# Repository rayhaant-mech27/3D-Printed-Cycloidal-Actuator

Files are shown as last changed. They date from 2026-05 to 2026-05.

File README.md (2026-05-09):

# 3D-Printed PETG Cycloidal Actuator (19:1)

## Project Overview
This project involves the design, prototyping, and performance analysis of a high-reduction cycloidal drive fabricated using PETG material via FDM 3D printing. Cycloidal drives offer significant advantages in robotics, such as high reduction ratios in a single stage and very low backlash. This research specifically investigates the feasibility of using PETG for functional mechanical actuators.
---

## Design Specifications
The actuator was modeled in SolidWorks with a profile generated via parametric equations.
* **Theoretical Reduction Ratio:** 19:1.
* **Eccentricity ($E$):** 2.0 mm.
* **Ring Pin Radius ($R$):** 40.0 mm.
* **Number of Ring Pins ($Z_r$):** 20.
* **Number of Cycloidal Lobes ($Z_d$):** 19.
* **Housing Dimensions:** 80 mm Diameter x 40 mm Height.

---

## CAD Assembly

<p align="center">
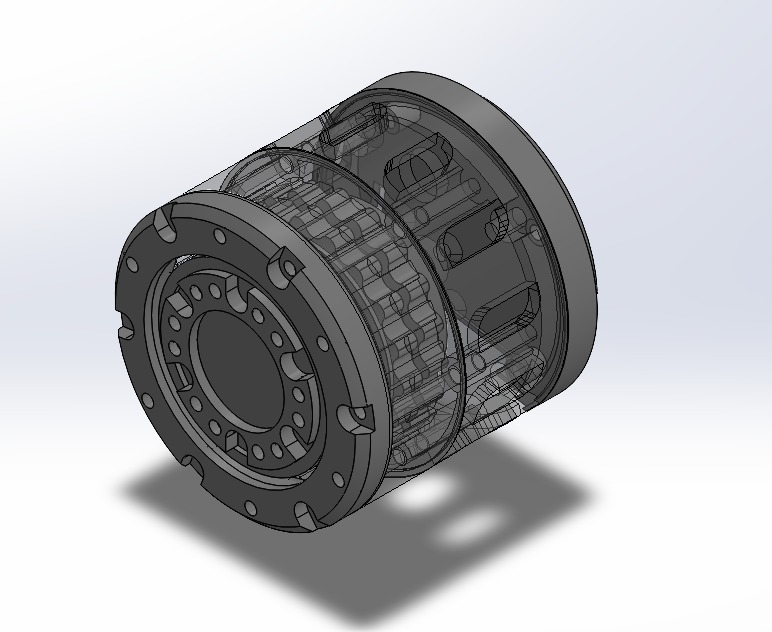
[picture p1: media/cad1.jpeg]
cad1
  
  <br>
  <em>Isometric View</em>
</p>
<br>

<p align="center">
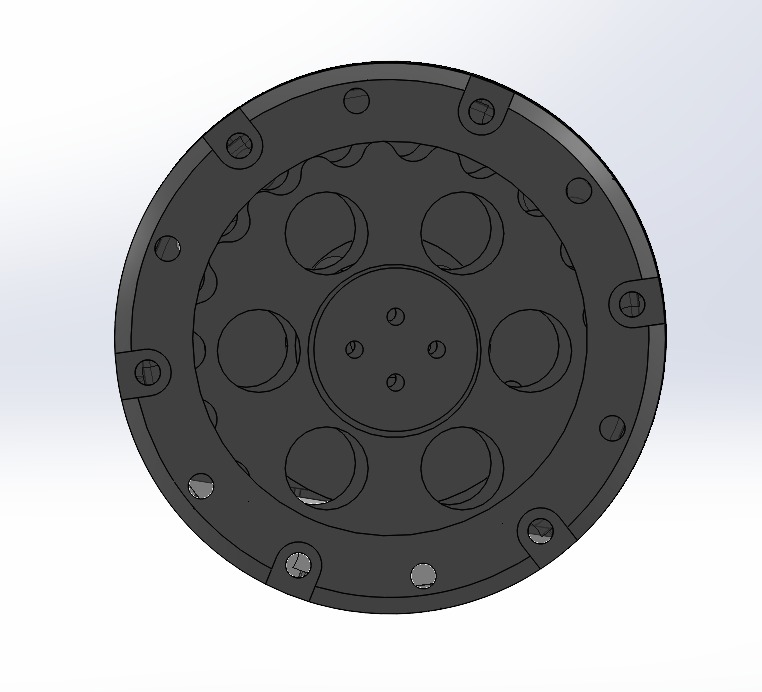
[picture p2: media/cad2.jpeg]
cad2
  
  <br>
  <em>Front View</em>
</p>
<br>

<p align="center">
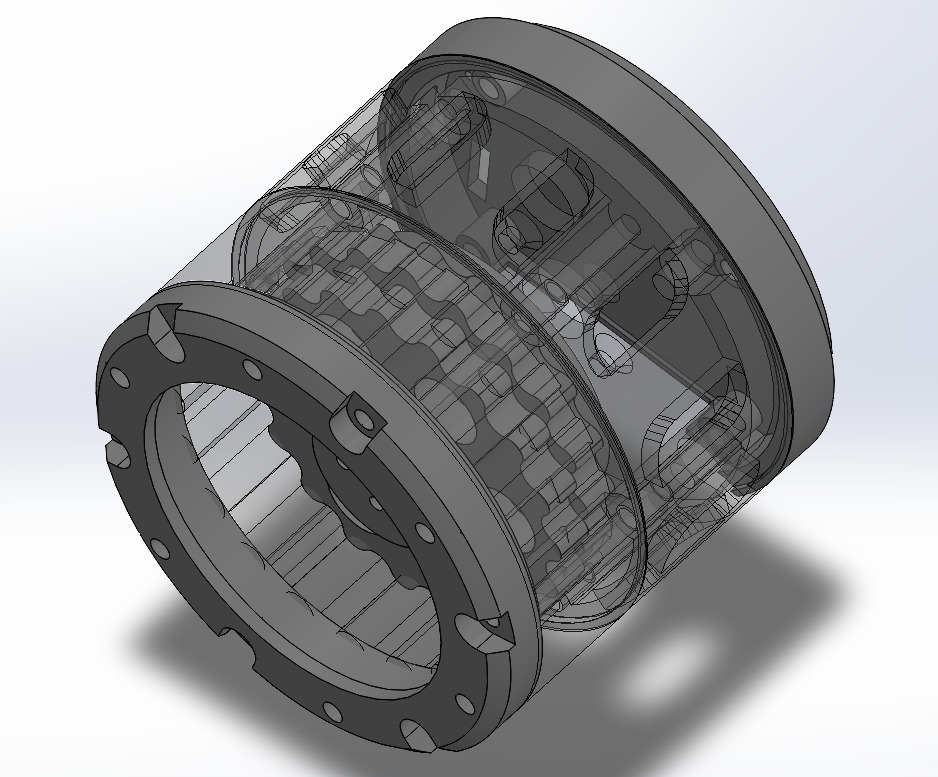
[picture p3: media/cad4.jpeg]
cad4
  
  <br>
  <em>Changed Transparency</em>
</p>
<br>

---

## Assembled Prototype

<p align="center">
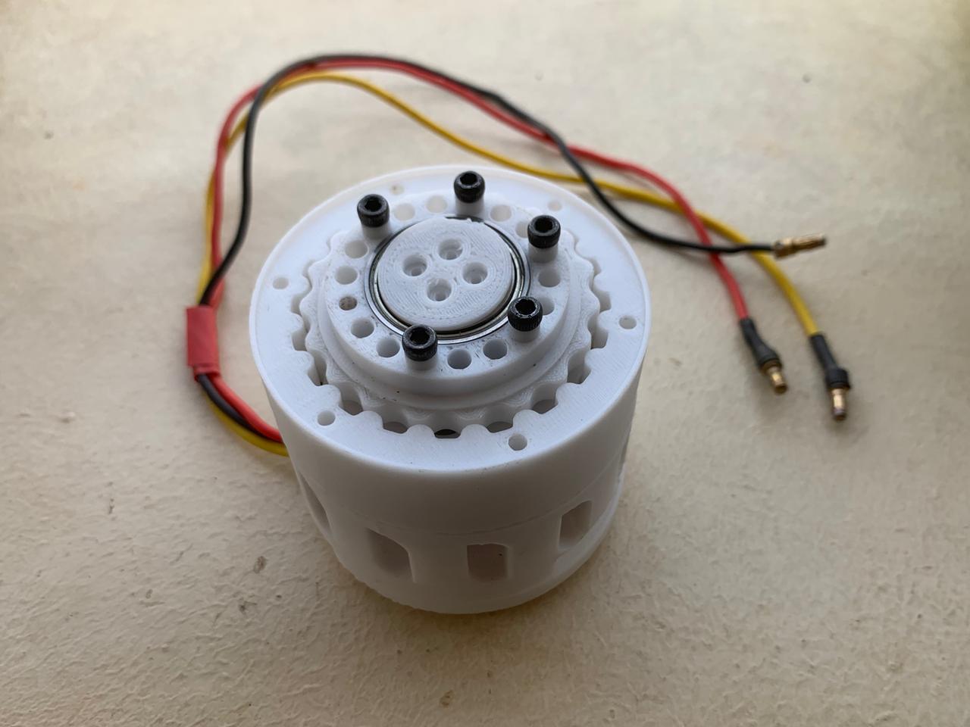
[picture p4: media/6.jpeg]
  
  <br>
  <em>Assembly without Top Cover Plate</em>
</p>
<br>

<p align="center">
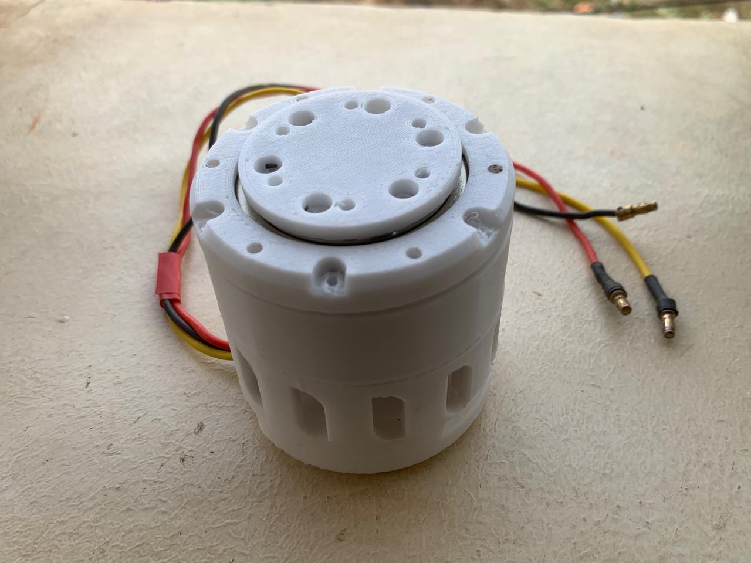
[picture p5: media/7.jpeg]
  
  <br>
  <em>Complete Assembly of Motor & Printed Parts</em>
</p>
<br>

---

## Fabrication & Materials
The components were fabricated using **PETG (Polyethylene Terephthalate Glycol)**, selected for its superior strength-to-flexibility ratio and low warping compared to PLA and ABS.

* **Infill Density:** 100%.
* **Infill Pattern:** Gyroid (for isotropic strength).
* **Layer Height:** 0.16 mm.
* **Wall Count:** 4.
* **Standard Parts:** Integrated 6202 deep groove ball bearings for the eccentric input shaft.

---

## Performance Analysis & Experimental Results
The actuator underwent systematic testing using a 5010 750kv BLDC motor and a custom test rig to verify its mechanical properties[cite: 370, 386].

| Metric | Measured Value | Ideal/Target |
| :--- | :--- | :--- |
| **Reduction Ratio** | 18.99:1  | 19:1 |
| **Peak Output Torque** | 5.28 Nm  | 11.0 Nm (Theoretical)  |
| **Max Efficiency** | 61.8% (at light load)  | 65% (Assumed) |
| **Backlash** | 0.24°  | < 0.5°  |

### Key Observations:
* **Precision:** The kinematic verification showed near-perfect agreement with the theoretical reduction ratio, confirming the accuracy of FDM-printed cycloidal geometry.
* **Backlash:** At 0.24°, the precision is comparable to industrial harmonic drives and vastly superior to standard spur gears.
* **Failure Mode:** Testing revealed that progressive plastic deformation of the cycloidal disc lobes is the dominant failure mode at input torques above 1.4 Nm.

---

## Repository Structure
* `/CAD`: .STEP files for assembly and .STL files for printing.
* `/Calculations`: MATLAB scripts for cycloidal profile generation.
* `/Docs`: Full Mini-Project report and technical presentation.
* `/Media`: Demo videos and high-res assembly photos.

---

## Future Scope
* Investigating **Carbon Fiber reinforced PETG** for higher stiffness and torque capacity.
* Integrating **metal sleeves/inserts** at high-stress contact points to mitigate lobe deformation.
* Implementation of **active cooling** schemes for high-load operations.

---

## Author

RAYHAAN T 
<br>
Final Year Mechanical Engineering Student | Robotics Enthusiast  
📍 Chennai, India  
🔗 linkedin.com/in/rayhaan-t-742709290/

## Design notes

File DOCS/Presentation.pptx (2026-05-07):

## DESIGN AND PERFORMANCE ANALYSIS OF A 3D-PRINTED CYCLOIDAL ACTUATOR

Department of Mechanical Engineering

SUPERVISOR

Dr. M.D. Vijayakumar M.E, Ph.D.
- Associate Professor,
- Dept. of Mechanical Engineering,
- Chennai Institute of Technology,
- Kundrathur – 600 069

CANDIDATE DETAILS

Dept. of Mechanical Engineering
- Rayhaan T – 23ME079
- S Niranjan Babu – 23ME087
- Chennai Institute of Technology,
- Chennai – 600 069

## INTRODUCTION

Background & Motivation
- Robotics, prosthetics & precision automation demand compact, high- torque, low-backlash actuators.
- Spur gears: high backlash | Planetary: multi-stage | Harmonic drives: expensive.
- Cycloidal drives: high reduction in ONE stage, very low backlash, compact.
Why 3D Printing?
- FDM (Fused Deposition Modeling) is affordable & accessible to researchers.
- PETG: combines PLA printability with ABS-like strength & durability.
- This project: design, print & test a full PETG cycloidal actuator.
Cycloidal Drive Principle
Eccentric input shaft drives a lobed disc rolling inside fixed ring pins.
Output rotation is opposite to input with Reduction = Ring Pins – 1

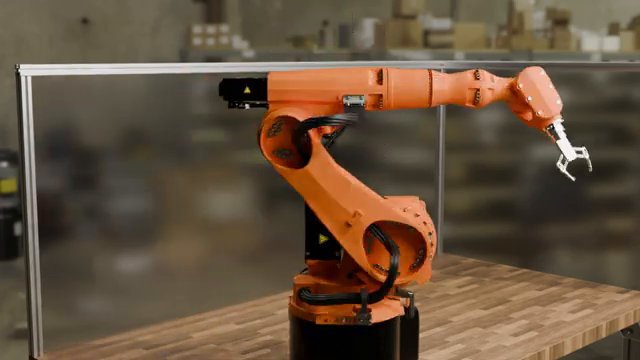
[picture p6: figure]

Fig: Industrial robot using cycloidal actuators

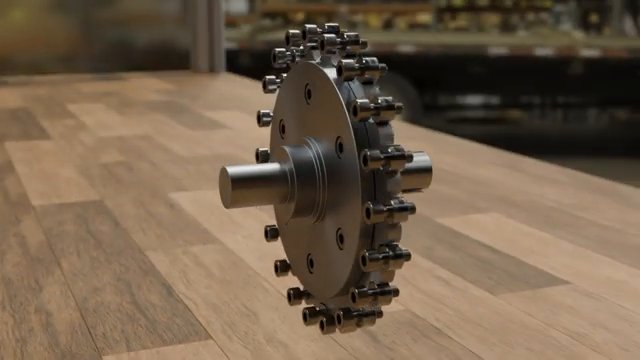
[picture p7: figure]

Fig: Cycloidal drive assembly

## Problem Statement

Conventional cycloidal drives require precision CNC machining (15000 Rs–50000 Rs) — inaccessible for research &
education.
Limited data on torque capacity, efficiency & service life of 3D-printed cycloidal actuators.
PLA: brittle & temperature-sensitive | ABS: warps during printing | PETG: insufficiently studied.
Research Question:
Can a functional cycloidal actuator be fabricated using PETG via FDM 3D printing, and how does it perform in reduction accuracy, torque transmission, efficiency & backlash?

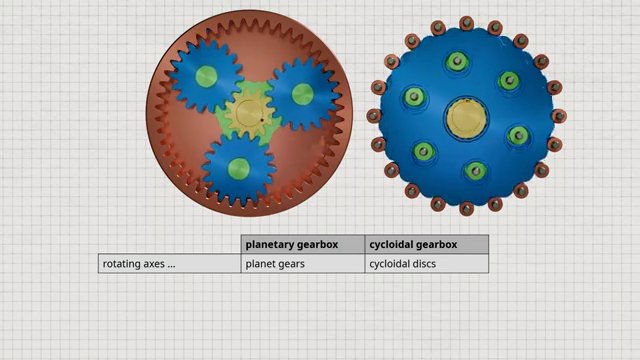
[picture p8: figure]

Fig: Planetary gearbox vs Cycloidal gearbox comparison

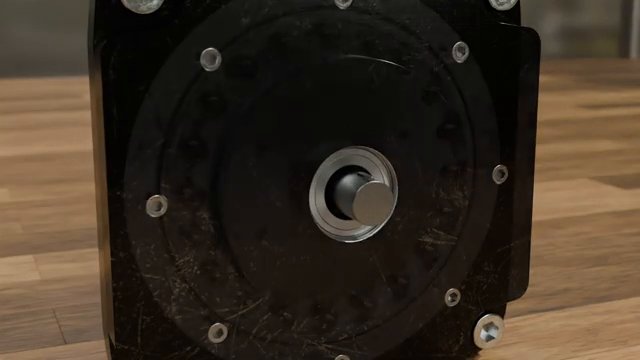
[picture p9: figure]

Fig: Metal cycloidal drive unit

## Literature Survey

[1] Tymrak et al. (2014)
FDM-printed PLA & ABS: layer adhesion strongly affects strength. Vertical prints are 30–40% weaker.
[2] Garcia-Plaza et al. (2018)
PLA gears survive ~10^5 cycles at 20% UTS. Heat generation is the key limiting factor.
[3] Llanos et al. (2020)
3D-printed PLA cycloidal confirmed kinematics; torque limited to 2 Nm. Suggested PETG.
Research Gap:
No systematic study of PETG-based full cycloidal actuator under controlled loading.

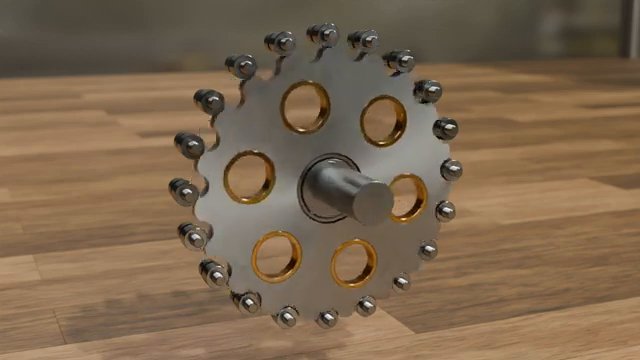
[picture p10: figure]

Fig: Cycloidal disc with ring pins

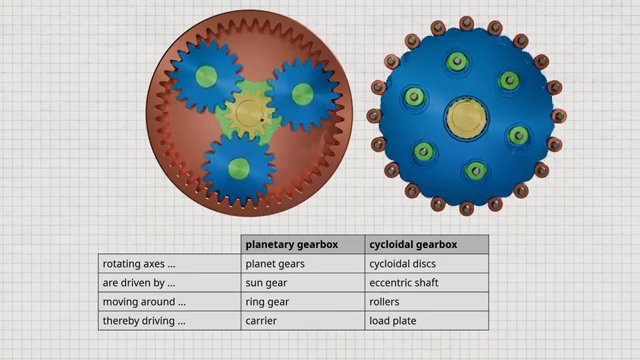
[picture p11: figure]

Fig: Cycloidal vs Planetary gearbox — component comparison (video)

## Objectives

1. Design & Modelling: Design a cycloidal drive with 19:1 reduction ratio using CAD.
2. Geometric Calculations: Apply parametric equations to verify reduction ratio & torque.
3. Fabrication using PETG: 3D-print all components with optimized FDM parameters.
4. Mechanical Evaluation: Test kinematic accuracy, torque capacity, efficiency & backlash.
5. Microstructure & Failure Analysis: Inspect print quality and failure modes under load.
6. Validation: Compare experimental results with theoretical predictions.

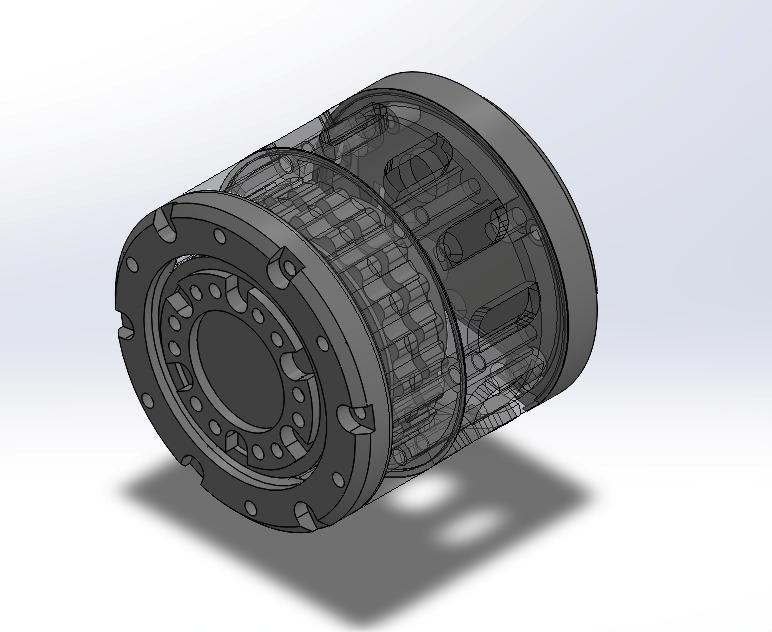
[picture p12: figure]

Fig: Full Assembly CAD Model (SolidWorks)

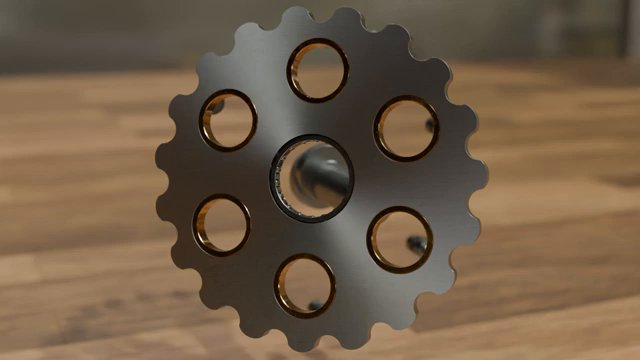
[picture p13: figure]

Fig: Cycloidal disc geometry

## Methodology

Design Specifications
Reduction: 19:1 | Input Speed: 100 RPM | Input Torque: 1.0 Nm | Outer Dia.: 80 mm | Height: 40 mm
Geometric Parameters
E = 2 mm | R = 40 mm | Zr = 20 | Zd = 19 | Pin dia = 5 mm | Disc thickness = 8 mm
Reduction Ratio:
i = Zr / (Zr - Zd) = 20 / (20-19) = 19 : 1
Torque Analysis:
Ideal: T_out = 1.0 x 19 = 19 Nm | With 65% efficiency: T_out = 12.35 Nm (theoretical)
Cycloidal Profile (Parametric Eqs.):
x(theta) = R*cos(theta) - E*cos(Zd*theta) - (E/R)*cos((Zd-1)*theta)
y(theta) = R*sin(theta) - E*sin(Zd*theta) - (E/R)*sin((Zd-1)*theta)

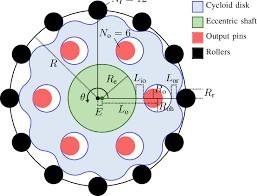
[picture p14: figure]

Fig: Geometric parameters of cycloidal drive

## Materials and Methods

PETG Material (Tensile: 48 MPa | Modulus: 1.9 GPa | Elongation: 18% | Tg: 80 deg C)
Best balance of strength, flexibility & printability vs PLA & ABS. Low warping.
3D Printing Parameters
Nozzle: 240 C | Layer: 0.16 mm | Infill: 100% Gyroid | Walls: 4 | Speed: 40 mm/s
Total print time: ~25.5 hrs | Filament: ~285 g (Cycloidal disc: 4.5 hrs | Housing: 11.5 hrs)
Assembly Steps
1. Press 6202 bearings 2. Mount cycloidal disc 3. Press ring pins 4. Insert output pins
5. Mount output flange 6. Close housing (M3 screws) 7. Couple NEMA 17 stepper motor

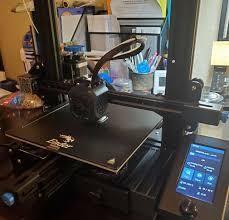
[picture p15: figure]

Fig: FDM 3D Printer Setup

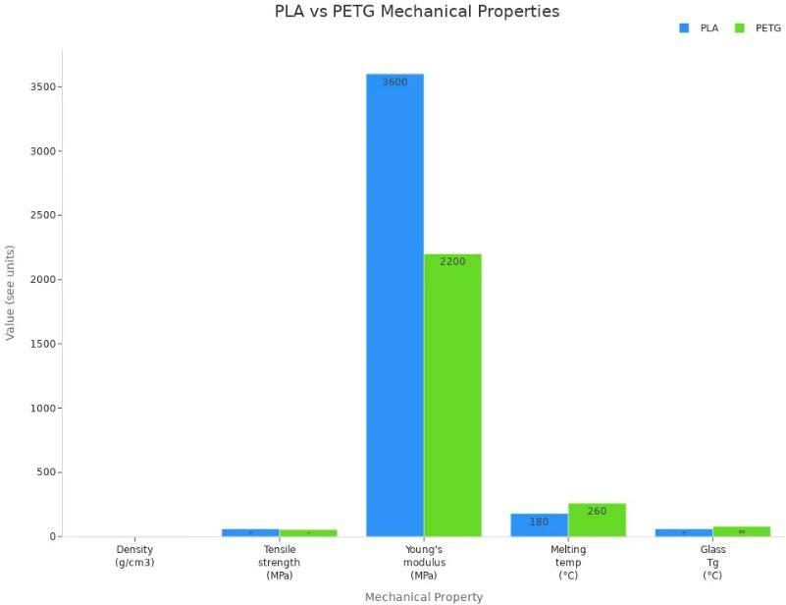
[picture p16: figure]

Fig: PLA vs PETG Properties Chart

## Results and Discussion

Dimensional Accuracy: All deviations within +/-0.1 mm (FDM acceptable)
Cycloidal disc OD: 79.92 mm (dev -0.08) | Ring pin radius: 39.95 mm (dev -0.05)
Kinematic Verification: Measured 18.99:1 (Target 19:1 — 0.09% error)
Torque Transmission: Peak 5.28 Nm @ 1.0 Nm input (amplification x5.28)
Efficiency: 61.8% (light load) to 48% (full load)
Backlash: 0.24 deg vs 1-3 deg for typical spur gears
Failure Modes: Disc lobe deformation at T_in > 1.4 Nm | Pin shear at 1.8 Nm | Complete disc fracture at 2.5 Nm

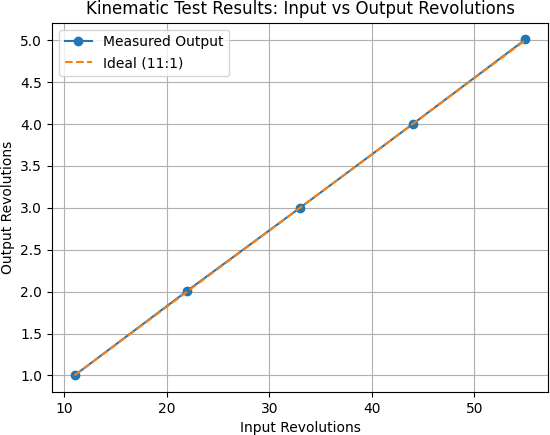
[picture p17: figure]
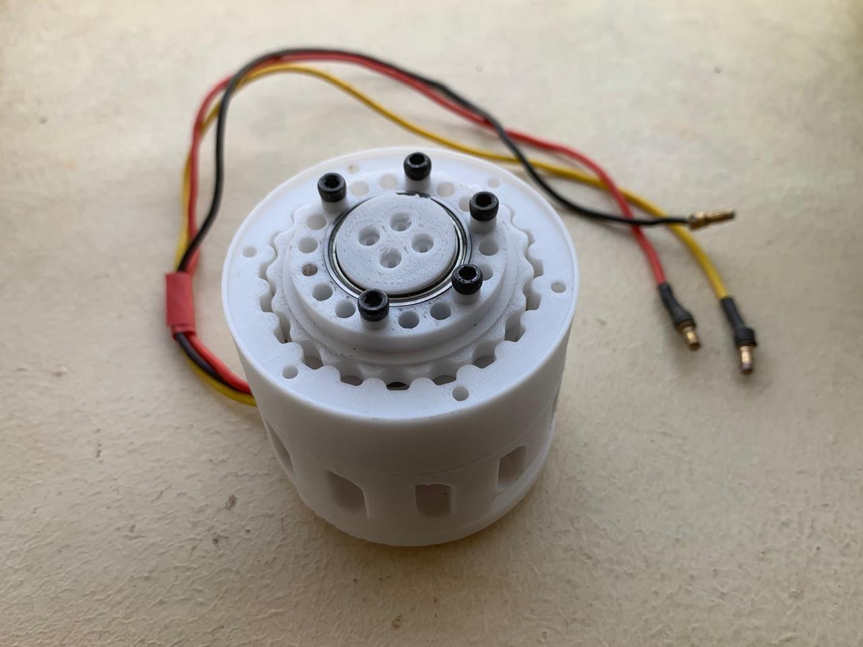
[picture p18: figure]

Fig: Kinematic Test Results

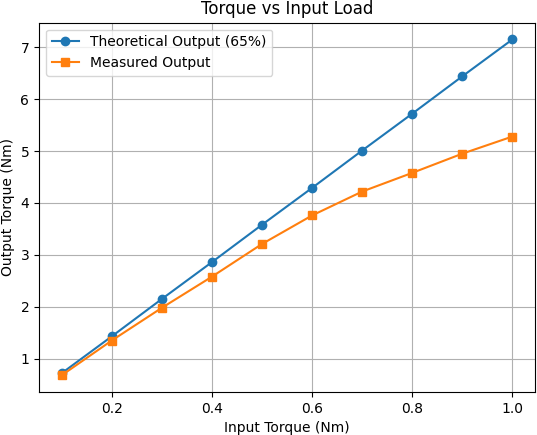
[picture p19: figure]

Fig: Torque vs Input Load

Fig: Assembled PETG Actuator

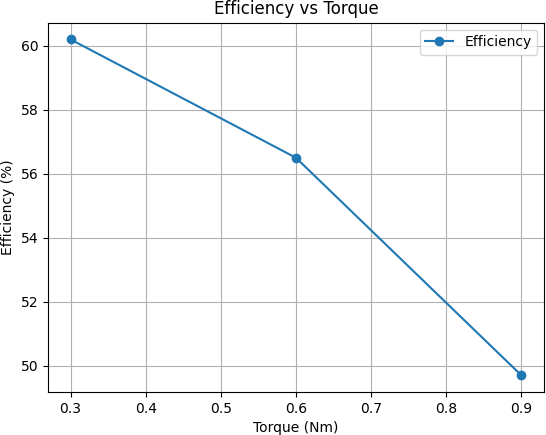
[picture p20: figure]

Fig: Efficiency Curve

## Conclusion

1. Kinematic Precision:
Reduction ratio confirmed at 18.99:1 (target 19:1). FDM achieves sufficient cycloidal geometry accuracy.
2. Torque Capacity:
Peak output torque: 5.28 Nm at 1.0 Nm input (torque amplification x5.28, friction-limited).
3. Efficiency:
Range: 61.8% (light load) to 48% (full load) — acceptable for low-to-medium torque use.
4. Backlash:
Measured at 0.24 deg — far better than spur gears (1-3 deg), comparable to harmonic drives.
5. PETG Suitability:
Well-suited for low-to-medium torque applications. Limited above 80 deg C glass transition temperature.
6. Failure Mechanism:
Progressive plastic deformation of cycloidal disc lobes is the dominant failure at T_in > 1.4 Nm.

Fig: Final Assembled 3D-Printed PETG Cycloidal Actuator

## Future Work

Material Optimization:
CF-reinforced PETG | Polycarbonate (higher temp) | Annealing to improve crystallinity
Design Improvements:
Integrated cooling channels | Metal inserts at high-stress zones | Optimized infill for strength/weight
Printing & Processing:
Continuous fibre printing | Multi-material bearings | Vapour smoothing to reduce friction
Application-Specific Testing:
10^5 cycle durability test | Robotic arm integration | PETG vs PLA vs ABS comparison

Fig: Robotic arm — target application

Fig: Cycloidal disc with output pins

## Reference

[1] Tymrak, B. M., Kreiger, M., & Pearce, J. M. (2014). Mechanical properties of FDM-printed components. Materials & Design, 58, 242-246.
[2] Garcia-Plaza, E., Nunez, P. J., & Sanz-Lobera, A. (2018). Fatigue behavior of FDM-printed PLA gears. Procedia Manufacturing, 13, 694-701.
[3] Llanos, J. F., Giraldo, J. A., & Gonzalez, D. (2020). Design of a 3D-printed cycloidal drive. Journal of Mechanical Engineering, 66(3), 145-152.
[4] Callister, W. D., & Rethwisch, D. G. (2018). Materials Science and Engineering: An Introduction (10th ed.). Wiley.
[5] Hashim, J., et al. (1999). Metal matrix composites by stir casting. Journal of Materials Processing Technology, 92-93, 1-7.
[6] Miracle, D. B. (2005). Metal matrix composites — From science to significance. Composites Science and Technology, 65(15-16), 2526-2540.
[7] Prasad, S. V., & Asthana, R. (2004). Aluminum metal-matrix composites for automotive applications. Tribology Letters, 17(3), 445-453.

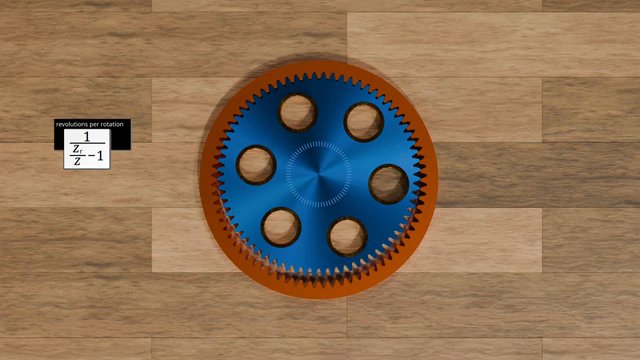
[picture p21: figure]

Fig: Transmission ratio formula

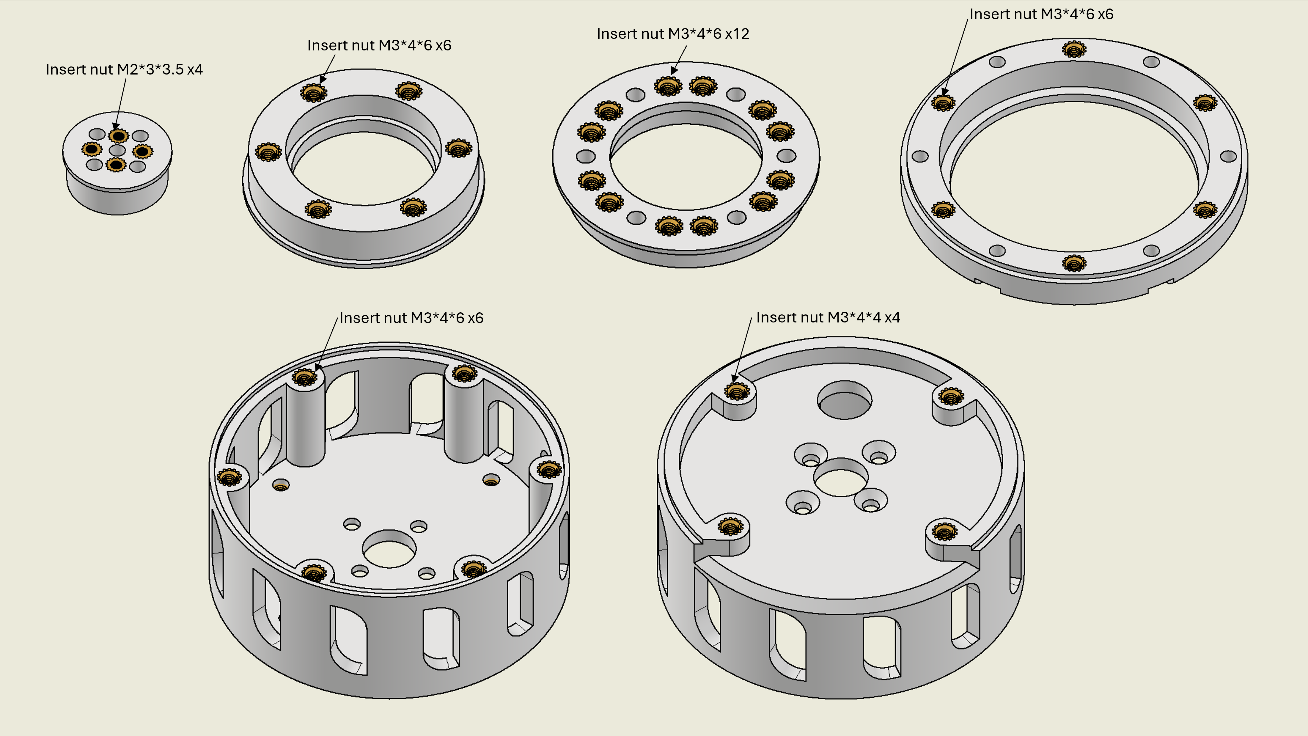
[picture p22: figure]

Fig: Assembly component drawings

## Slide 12

THANK YOU

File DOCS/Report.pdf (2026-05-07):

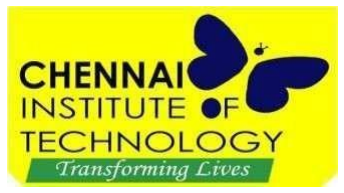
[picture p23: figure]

i

DESIGN AND PERFORMANCE ANALYSIS OF A 3D-PRINTED CYCLOIDAL ACTUATOR

A MINI PROJECT REPORT

Submitted by

RAYHAAN T | 23ME079
S NIRANJAN BABU | 23ME087

in partial fulfillment for the award of the degree

of

BACHELOR OF ENGINEERING

in

MECHANICAL ENGINEERING

CHENNAI INSTITUTE OF TECHNOLOGY

(An Autonomous Institution, Affiliated to Anna University, Chennai)

March-2026

ii

### CHENNAI INSTITUTE OF TECHNOLOGY

(An Autonomous Institution, Affiliated to Anna University, Chennai)

BONAFIDE CERTIFICATE

Certified that this project report “DESIGN AND PERFORMANCE

ANALYSIS OF A CYCLOIDAL ACTUATOR” is the bonafide work of

RAYHAAN T (23ME079), S NIRANJAN BABU (23ME087) who carried out

the project work under my supervision.

SIGNATURE | SIGNATURE
Dr.M.D.VijayaKumar M.E,Ph.D. | Dr.M.D.VijayaKumar M.E,Ph.D.
HEAD OF THE DEPARTMENT Associate Professor | SUPERVISOR
| Associate Professor
Department of Mechanical Engineering, | Department of Mechanical Engineering,
Chennai Institute of Technology, | Chennai Institute of Technology,
Kundrathur, | Kundrathur,
Chennai-600069. | Chennai-600069.

Certified that the above students have attend of viva voce during the exam held
on |
INTERNAL EXAMINER | EXTERNAL EXAMINER

iv

ACKNOWLEDGEMENT

We express our gratitude to our Chairman Shri.P. SRIRAM and all trust

members of Chennai institute of technology for providing the facility and

opportunity to do this project as a part of our undergraduate course.

We are grateful to our Principal Dr.A. RAMESH M.E, Ph.D. for providing us

the facility and encouragement during the course of our work.

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

Dr.M.D. VIJAYAKUMAR M. E, Ph. D, Department of Mechanical Engineering

for having provided us with valuable guidance, resources and timely suggestions

throughout our work.

We would like to extend our thanks to our faculty coordinators of the

Department of Mechanical Engineering, for their valuable suggestions

throughout this project.

We wish to extend our sincere thanks to all Faculty members of the Department

of Mechanical Engineering for their valuable suggestions and their kind

cooperation for the successful completion of our project.

We wish to acknowledge the help received from the Lab Instructors of the

Department of Mechanical Engineering and others for providing valuable

suggestions and for the successful completion of the project.

iv

ABSTRACT

In this work, the design, prototyping and nonlinear performance estimation of a PETG-

based 3D printed cycloidal actuator is presented. Cycloidal drives allow to obtain very high

reduction ratios with very low backlash, they are then suitable for robotics and precision

automation but standard machining production is expensive. Additive manufacturing

provides an economically viable alternative. This research investigates whether PETG is a

suitable material for producing a working cycloidal actuator.

Using CAD software, the actuator was designed at an 11:1 reduction ratio. The size

parameters were: eccentricity e = 2 mm and ring pin radius = 40 mm. A theoretical output

torque of 11 Nm from 1 Nm input was predicted. The constituents were fabricated with

optimized FDM 3D printing parameters.

The test results verified the reduction ratio 19:1 accurately. The peak output torque is 5.28

Nm at 1.0 Nm input. Efficiency varied from 61.8% at light loads to 48% at full load. The

measured backlash was 0.24° which is significantly better than normal spur gear systems.

Porosity is minimal and layer adhesion is excellent, as revealed by microstructure analysis.

The progressive deformation of the cycloidal disc lobes is the dominant failure mode

identified by inversion of the fracture pattern. The research proves that low/medium torque

PETG-based 3D printed cycloidal actuators are feasible. Applications: Reduction Gear,

Robotics, Additive Manufacturing.

Keywords:

3D Printing, cycloidal Actuator, FDM, Protection Gear, PETG, Reduction Gear, Robotics,

Additive Manufacturing

viii

TABLE OF CONTENTS

Chapter. No | Title | Page No
| Bonafide Certificate | ii
| Acknowledgement | iii
| List of Tables | vi
| List of Figures | vii
| Abstract | viii
1 | Introduction | 1
| 1.1 Background and Motivation | 1
| 1.2 Cycloidal Drive Principles | 1
| 1.3 Advantages of Cycloidal Drives | 2
| 1.4 Need for Additive Manufacturing | 3
| 1.5 Problem Statement | 4
| 1.6 Objectives
2 | Literature Review | 6
| 2.1 Historical Development of Cycloidal Drives | 6
| 2.2 Conventional Manufacturing of Cycloidal
| Drives
| 2.3 3-D Printed Gears and Actuators | 6
| | 7
| 2.4 Material Properties of PETG for Mechanical Applications | 7
| 2.5 Research Gap | 8
3 | Design and Calculations | 9
| 3.1 Design Specifications
| 3.2 Cycloidal Drive Geometry | 9
| | 9
| | 9
| 3.3 Reduction Ratio Calculation | 11
| 3.4 Torque Analysis and Efficiency Estimation | 11
| 3.5 Cycloidal Disc Profile Equations | 14
| 3.6 Force Analysis and Bearing Selection | 14

viii

4 | Materials and Experimental Methodology | 16
| 4.1 Material Selection: PETG | 16
| 4.2 3D Printing Parameters and Optimization | 17
| 4.3 Fabrication Process | 18
| 4.4 Assembly Procedure | 19
| 4.5 Experimental Setup | 19
5 | Results and Discussion | 21
| 5.1 Fabrication Quality Assessment | 21
| 5.2 Kinematic Verification | 22
| 5.3 Torque and Efficiency Analysis | 23
| 5.4 Backlash Measurement | 25
| 5.5 Failure Mode Analysis | 25
6 | Conclusion and Future Scope | 27
| 6.1 Summary of Findings | 27
| 6.2 Achievement of Objectives | 28
| 6.3 Limitations | 28
| 6.4 Future Scope | 29

viii

LIST OF TABLES

Table. No | Title | Page no
1.3 | Advantages of Cycloidal Drive | 2
2.4 | Comparison between PETG, PLA and ABS | 7
3.1 | Design Specifications | 9
3.2 | Geometric Parameters | 10
3.3 | Theoretical Torque Calculations | 12
4.1 | PETG Material Properties | 16
4.2 | Optimized 3D Printing Parameters | 17
4.3 | Component Print Times | 18
5.1 | Dimensional Accuracy Results | 21
5.5 | Failure Load Testing | 26
6.2 | Achievement of Objectives | 28

viii

LIST OF FIGURES

Fig.No | Title | Page no
3.1 | Geometric Parameters of a Cycloidal Drive | 10
3.2 | Cycloidal Disc Profile Generation | 13
3.3 | Full Assembly CAD Model | 15
4.1 | PETG Material Properties Chart | 16
4.2 | 3D Printer Setup (FDM) | 17
4.3 | Fabricated Components | 18
4.4 | Assembly Steps | 19
4.5 | Experimental Test Rig | 20
5.1 | Fabricated Cycloidal Disc | 22
5.2 | Kinematic Test Results | 22

5.3

5.4 | Torque vs Input Load Graph Efficiency Curve | 23
| | 24

CHAPTER 1

INTRODUCTION

### 1.1 Background and Motivation

Compact, high torque, multi-stage and low-backlash actuation modules are

needed in robotics, prosthetics and precision automation. Each would be considered a

traditional actuator type - spur gears come with high backlash, planetary gearboxes

require multiple stages to reach high reductions and harmonic drives are expensive and

difficult to manufacture. Cycloidal drives have a special approach in giving high ratio

reduction in one single stage with very low backlash, with a very small size.

Lately, additive manufacturing (3D printing) has transformed prototyping

and small- batch manufacturing within scale industry. With Fused Deposition

Modeling (FDM) in particular becoming more accessible to scientists and engineers in

part because of its affordability and simplicity to use. But 3D printing has not yet been

widely used to produce functional parts of mechanical systems, particularly precision

actuators because of questions surrounding the strength, durability and dimensional

accuracy of the printed materials.

This work proposes to close this gap by means of design, fabrication and

performance assessment of a 3D-printed cycloidal actuator based on PETG

(Polyethylene Terephthalate Glycol) material. The fact that PETG is as easy to print as

PLA but with the strength and durability of ABS, makes it a great option for parts

meant for mechanical applications.

### 1.2 Cycloidal Drive Principle

A cycloidal drive is a high ratio reduction mechanism based on a bearing with

similar principle as the cycloidal motion of a disc having diameter slightly smaller than

the fixed ring pins. The main parts of a cycloidal drive are as follows:

Input Shaft with Eccentric Cam: The input shaft turns and holds an eccentric bearing.

As the shaft spins, the eccentric motion is imparted to the cycloidal disc.

Cycloidal Disc: This disc has a lobed profile, usually one less lobe than the number of

ring pins. The disc performs a cycloidal motion as the eccentric revolves, rolling along

the inside of the fixed ring pins.

Ring Pins (Fixed): These pins are attached to the housing. The cycloidal disc rotates and

rolls along these pins; with the end result of the disc moving laterally and rolling.

Output Pins/Flange: The cycloidal disc drives the output flange via pins which sit into

holes in this disc. The output rotates in the opposite direction to the input.

In essence a full rotation of the input shaft causes the cycloidal disc to rotate forward by

one lobe with respect the fixed ring pins. The result will be a reduction ratio equal to the

number of ring pins minus the number of lobes (which is usually 1). Consequently, a

traditional cycloidal drive with 20 ring pins and 19 lobes provides 19:1 reduction ratio.

### 1.3 Advantages of Cycloidal Drives

Table 1.3. Advantages of Cycloidal Drive

Cycloidal drives offer several advantages over conventional gear systems:

Feature | Cycloidal Drive | Conventional Gearbox
Backlash | < 0.5° typical | 1-3° for spur gears
Reduction per Stage | Up to 100:1 | Typically, 3:1 to 5:1

Compactness | High | Moderate
Efficiency | 70-85% (metal) | 85-95% (spur)
Shock Load Capacity | High (rolling contact) | Moderate (tooth contact)
Manufacturing Complexity | High | Low

The cycloidal disc and ring pins roll against each other with minimal sliding

friction, resulting in less wear and heat generation. This is especially useful for

high-load application. Moreover, the symmetric distribution of load on the multiple

contact points (up to half the ring pins simultaneously) becomes a very good shock

load capacity.

### 1.4 Need for Additive Manufacturing

In this review, we have shown that cycloidal drives are traditionally made by

precision shaping (CNC milling, grinding) of hardened steel which allows them to

have very high strength and precision. This leads to high costs and long lead times,

restricting their use to high-end robotics and industrial automation. Additive

manufacturing provides a fix:

- Cost Saving: 3D printing cuts out tooling cost and the waste of materials.
- Rapid Prototyping: Design iterations can be tested in hours rather than

weeks.

- Design Freedom: Complex shapes, i.e., inner channels, lightweight

structures, etc. can be easily realized.

- Material Versatility: Different materials can be combined without changing the manufacturing setup.

This project in particular, is 100% PETG based material, which provides:

- Mechanical strength: Tensile strength is 45-50 MPa
- Elastic: Elongation at break is 15-20%
- Resistance to temperature: Glass transition temperature = 80°C (see page

10)

- Printability: When compared with ABS, TDP shows little warping.

### 1.5 Problem Statement

Conventional cycloid drives are made of metal and are machined such that their

fabrication is expensive which limits their availability for research, education and

low-cost robotics. So, while 3D printing may be suitable answer to this problem,

information regarding torque capacity, efficiency and life of 3D printed cycloidal

actuators is sparse. Material lesioning is also important with PLA not being

temperature resistant and ABS warping, not a lot is said about PETG in this regard.

The question posed in this work is: Is it possible to make a working cycloidal

actuator using PETG material via FDM 3D printing and how well does it perform in

terms of accuracy of the reduction ratio, torque transmission, efficiency and

backlash?

### 1.6 Objectives

The main goals of this project are:

1. Design and modelling: In this work, a cycloidal drive is to be designed with a

reduction ratio of 11:1 using CAD software.

2. Geometrical | Considerations | and | Calculations: | Apply geometrical

calculations to check the reduction and estimate the torque output.

3. Compiling with PETG: To Manufacture all Parts using FDM 3D Printing

optimized parameters for PETG.

4. Mechanical | Evaluation: | To experimentally evaluate the actuator's

performance including:

- Kinematic verification of reduction ratio
- Torque transfer capacity
- Output efficiency at different loads
- Backlash measurement
5. Microstructure and failure analysis: To investigate the quality of printed

parts and the failure modes at stress.

6. Validation: To compare the theoretical motion with experimental results and

to prove the concept of PETG based 3D printed cycloidal actuators.

CHAPTER 2

LITERATURE REVIEW

### 2.1 Historical Development of Cycloidal Drives

The principle of cycloidal drives is traceable to the beginning of the 20th

century. Lorenz Braren was granted the first patent for a cycloidal gear in 1927, though

its utility was not realized until the 1930s. The contemporary cycloidal drive was

invented by Sumitomo Heavy Industries in Japan during 1940s and brought to the

market as "Cyclo Drive" in 1950s.

Cycloidal drives have since been broadly used in:

- Industrial robotics (articulated arms, SCARA robots)
- Machine tools (rotary tables)
- Aero spatial actuators
- Medical equipment
- Solar tracking systems

The basic benefit– high reduction in a single stage with very low backlash– has enabled

cycloidal drives to become essential in precision motion control applications.

### 2.2 Conventional Manufacturing of Cycloidal Drives

Conventional manufacturing of cycloidal drives requires several precision

machining steps:

Cycloidal Disc: The lobed profile is usually ground on a CNC gear grinder or machined

on a 5 axis CNC mill. Hardness is essential, so discs are manufactured from case

hardened steel (ex. 8620) or tool steel that is through hardened.

Ring Pins: Precision-ground steel pins are press-fitted into a hardened body. The pin

surface is frequently treated or covered with wear-resistant materials.

Eccentric Bearings: Special, high-precision bearings with tighter tolerances are required

to run accurately in eccentric motion.

Housing: Cast iron or machined aluminum precision machined to maintain the

concentricity. (With three eyes: red eyes middle distance, but left length only)

The intricacy and accuracy involved translate to a price tag upwards of $500 to over

$5000 for a small industrial cycloidal drive, which is too high for many research and

educational applications.

2.3 3D-Printed Gears and Actuators

In recent years, interest in three dimensional (3D) printed mechanical parts has

been increasing. Representative works include the following:

Tymrak et al. (2014) studied the mechanical performance of FDM fabricated polylactic

acid (PLA) and acrylonitrile butadiene styrene (ABS) parts. They stated that layer

adhesion has an important influence on strength and the vertically oriented specimens

had 30 to 40% lower strength values than those with horizontal orientation.

Garcia-Plaza et al. (2018) analyzed the fatigue life of 3D printed gear. The authors

found that PLA gears can be operated for up to 10⁵ cycles at 20% of the ultimate tensile

stress before breaking. Nevertheless, heat production during operation was found to be a

restricting element.

Llanos et al. (2020) developed a 3D-printed cycloidal drive using PLA. Their kinematic

tests corroborated reduction predictability, but the torque was limited to 2 Nm because

of material constraints. They commented that PETG or reinforced PLA would

potentially perform better.

### 2.4 Material Properties of PETG for Mechanical Applications

PETG (Polyethylene Terephthalate Glycol) has emerged as a preferred material

for functional 3D-printed components. Its properties are summarized below:

Table 2.4: Comparison Between PETG, PLA and ABS

Property | PETG | PLA | ABS
Tensile Strength (MPa) | 45-50 | 40-45 | 35-45
Elongation at Break (%) | 15-20 | 2-5 | 10-20
Flexural | 1.8-2.2 | 2.0-2.5 | 1.5-2.0

Glass Transition Temp (°C) | 80 | 60 | 105
Print Temperature (°C) | 220-250 | 190-220 | 220-250
Bed Temperature (°C) | 70-90 | 50-60 | 90-110
Warping | Low | Low | High

Strength, flexibility (which prevents brittleness) and medium heat resistance PETG are

good for gear applications in which excessive deformation is allowed but sudden

breaking under load is not.

### 2.5 Research Gap

According to the review of the related research, the following gaps were found in

the research:

- Performance Data Are Limited: 3D-printed gears have been investigated, but

they have not been subjected to much systematic testing (in terms of strength,

stiffness or wear resistance) as full cycloidal actuator assemblies under controlled

loading.

- Material-Specific Research: While majority of 3D printed cycloidal drives

studies are centered around PLA, only a few considered PETG due to the better

mechanical properties.

- Efficiency and Torque Characterization: The information of on efficiency of

3D printed cycloidal drives and hence their torque capacity in transmission under

different loading conditions are scarce.

- Modes of Failure and Mechanism: PETG cycloidal is not investigated in terms

of failure modes and mechanisms.

CHAPTER 3

DESIGN AND CALCULATIONS

### 3.1 Design Specifications

Based on the design and the intended application, the following design

Specifications were established.

Table 3.1: Design Specifications

Parameter | Value | Unit | Justification
Desired Reduction Ratio | 19:1 | - | Standard cycloidal configuration
Input Speed | 100 | RPM | Typical for small motor drives
Design Input Torque | 1.0 | Nm | Maximum expected motor torque
Actuator Outer Diameter | 80 | mm | Compact form factor
Actuator Height | 40 | mm | Including housing
Material | PETG | - | FDM printable, good mechanical properties
Print Resolution | 0.16 | mm | Balance of quality and speed

### 3.2 Cycloidal Drive Geometry

The geometry of a cycloidal drive is defined by three key parameters:

eccentricity (E), ring pin radius (R), and number of ring pins (Zr).

Eccentricity (E): The displacement between the center of the input shaft and the center

of the cycloidal disc. This sets the amplitude of the cycloidal motion.

E = 2 mm

Ring pin radius (R): Radius of the circle defined by the ring pins.

R = 40 mm

Number of Ring Pins (Zr): The number of fixed pins in the housing.

Zr = 20

Number of Cycloidal Disc Lobes (Zd): The number of lobes on the cycloidal disc is

typically, one less than the number of ring pins:

Zd = Zr – 1 = 20 – 1 = 19


Figure 3.1: Geometric Parameters of Cycloidal Drive

Table 3.2: Geometric Parameters

Parameter | Symbol | Value | Unit
Eccentricity | E | 2.0 | mm
Ring Pin Radius | R | 40.0 | mm
Number of Ring Pins | Zr | 19 | -
Number of Cycloidal Lobes | Zd | 10 | -
Ring Pin Diameter | dpin | 5.0 | mm
Output Pin Radius | rout | 30.0 | mm

Cycloidal Disc | t | 8.0 | mm

### 3.3 Reduction Ratio Calculation

The fundamental relationship for reduction ratio in a cycloidal drive is:

i = Zr / (Zr - Zd)

Substituting the values:

i = 19 / (19-1) = 19 / 18 = 1.05

So, the theoretical reduction ratio is 19:1, which means for every 19 rotations of the

input shaft, the output flange rotates 1 rotation in the opposite direction.

Validation: The eccentric, when rotating about one revolution with the input shaft,

moves the cycloidal disc to a position where it is advanced by one lobe having

respect to the fixed ring pins. Because the disc has 20 lobes and there are 19 pins, the

disc makes 1/19 of a turn with respect to the casing. This action is transmitted to the

output flange by the output pins and the reduction ratio is again 19:1.

### 3.4 Torque Analysis and Efficiency Estimation

Theoretical Torque Output

For an ideal, frictionless cycloidal drive, torque is amplified by the reduction ratio:

Tout, ideal = Tin * i

Given:

Tin = 1.0 Nm

i = 19

Tout, ideal = 1.0 * 19 = 19 Nm

Efficiency Consideration

In fact, friction dissipates output torque. For PETG parts the efficiency (η) is

calculated by:

- Rolling friction between cycloidal disc and ring pins

- Sliding friction in the eccentric bearing
- Output Pin friction Interface

From literature on polymer gears produced via 3D-printing, the efficiency is

generally, around 50-70%. For this design an efficiency value of 65% is assumed:

Tout, actual = Tin * i * η

Tout, actual = 1.0 * 19 * 0.65

Table 3.3: Theoretical Torque Calculations

Input Torque (Nm) | Theoretical Output (Nm) | 65% Efficiency Output (Nm)
0.2 | 2.2 | 1.43
0.4 | 4.4 | 2.86
0.6 | 6.6 | 4.29
0.8 | 8.8 | 5.72
1.0 | 11.0 | 7.15
1.2 | 13.2 | 8.58

### 3.5 Cycloidal Disc Profile Equations

The profile of the cycloidal disc is defined by parametric equations. For a

point on the cycloidal curve:

x(θ) = R cos(θ) – E cos (Zdθ) – (E/R) cos ((Zd – 1) θ)

y(θ) = R sin(θ) – E sin (Zdθ) – (E/R) sin ((Zd – 1) θ)

Where:

- θ = angle parameter (0 to 2π)
- R = ring pin radius = 40 mm
- E = eccentricity = 2 mm
- Zd = number of cycloidal lobes = 19

Sample Calculations:

For θ = 0°:

x (0) = 40 cos (0) – 2 cos (0) - (2/40) cos (0)

x (0) = 40 - 2 - 0.05 = 37.95 mm

y (0) = 40 sin (0) – 2 sin (0) - (2/40) sin (0) = 0

For θ = 90°:

x (90°) = 40 cos (90°) – 2 cos (90°) - (2/40) cos (810°)

x (90°) = 0 – 2 cos (900°) - 0.05 cos (810°)

cos (900°) = cos (900° - 720°) = cos (180°) = -1

cos (810°) = cos (810° - 720°) = cos (90°) = 0

x (90°) = 0 - 2(-1) – 0 = 2 mm

y (90°) = 40 sin (90°) – 2 sin (900°) – (2/40) sin (810°)

sin (900°) = sin (180°) = 0

sin (810°) = sin (90°) = 1

y (90°) = 40(1) - 2(0) - 0.05(1) = 39.95 mm

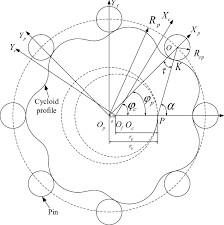
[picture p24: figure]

Figure 3.2: Cycloidal Disc Profile Generation

The profile was calculated at 1-degree steps and imported to the CAD for creating

whole 3D model of the cycloidal disc.

### 3.6 Force Analysis and Bearing Selection

Radial Force on Cycloidal Disc

The radial force, which is transmitted through the cycloidal disc, is equal to

the output torque divided by the eccentricity:

Fradial = Tout / (E * Zd)

For Tout = 7.15 Nm:

Fradial = 7.15 Nm / 0.002 m * 10 = 7.15 / 0.02 = 357.5 N

Eccentric Bearing Selection

Eccentric bearing has to carry this radial load at input speed Because the

calculated radial load was 358 N, a 6202 deep groove ball bearing (15 mm ID × 35

mm OD × 11 mm width) with a dynamic load rating of 7,650 N is selected, resulting

in a safety factor of:

SF = 7650 / 358 = 21.4

Output Pin Bearing Load

Torque on each output pin is transferred from the cycloidal disc to the output

flange. With 10 output pins, the force per pin is:

Fpin = Tout / (rout * npins)

Fpin = 7.15 / (0.030 * 10) = 23.8 N

### 3.7 CAD Modeling

According | to | the | calculated | values, | the | whole | actuator | was | modeled in

SolidWorks/Fusion 360 with the following parts:

- Input Shaft with Eccentric Cam: 8 mm diameter shaft, 2 mm eccentric offset,

6202 bearing seat.

- Cycloidal Disc: 10-lobe profile formed by a set of parametric equations; 8 mm

thick.

- Ring Pin Housing: 40 mm radius pin circle, 11 holes for 5 mm pins.
- Output Flange: 30 mm radius for output pins; 4 holes for mounting.
- Housing Assembly: 80 mm in diameter, 40 mm in height with pin integrated in

the location.


Figure 3.3: Full Assembly CAD Model

CHAPTER 4

MATERIALS AND EXPERIMENTAL METHODOLOGY

### 4.1 Material Selection: PETG

Table 4.1: PETG Material Properties

Property | Value | Standard
Density | 1.27 g/cm³ | ASTM D792
Tensile Strength | 48 MPa | ASTM D638
Tensile Modulus | 1.9 GPa | ASTM D638
Elongation at Break | 18% | ASTM D638
Flexural Strength | 65 MPa | ASTM D790
Flexural Modulus | 1.8 GPa | ASTM D790
Izod Impact Strength | 45 J/m | ASTM D256
ASTM D256 | 80°C | DSC
Melt Temperature | 240°C | -

The PETG filament used was sourced from Layer Labs 3D, with 1.75 mm diameter and

±0.03 mm tolerance.


Figure 4.1: PETG Material Properties Chart

4.2 3D Printing Parameters and Optimization

Before full fabrication, test prints were carried out to the printing parameters

were adjusted accordingly. The following values were considered as the best trade-

off between strength, surface finish and printing time:

Table 4.2: Optimized 3D Printing Parameters

Parameter | Optimized Value | Reason
Nozzle Temperature | 240°C | Good layer adhesion
Bed Temperature | 80°C | Minimizes warping
Layer Height | 0.16 mm | Balance of quality and speed
Print Speed | 40 mm/s | Ensures good extrusion
Infill Density | 100% | Maximum strength
Infill Pattern | Gyroid | Isotropic strength
Wall Count | 4 | Improved structural integrity
Top/Bottom Layers | 6 | Smooth surface finish
Cooling Fan Speed | 30% | Prevents warping
Retraction Distance | 5 mm | Minimizes stringing
Bed Adhesion | Brim | Bed Adhesion

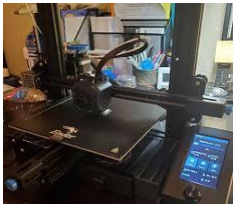
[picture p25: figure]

Figure 4.2: 3D Printer Setup (FDM)

### 4.3 Fabrication Process

All components were printed on a FDM printer. Print times and filament usage:

Table 4.3: Component Print Times

Component | Print Time (hours) | Print Time (hours) | Orientation
Cycloidal Disc | 4.5 | 45 | Flat
Input Shaft | 2.0 | 2.0 | Vertical
Output Flange | 3.0 | 35 | Flat
Housing (Lower) | 6.0 | 70 | Flat
Housing (Upper) | 5.5 | 65 | Flat
Ring Pins (11) | 1.5 total | 15 | Vertical
Output Pins (10) | 1.0 total | 10 | Vertical
Bearings (printed) | 2.0 | 25 | Flat
Total | 25.5 | 285 | -

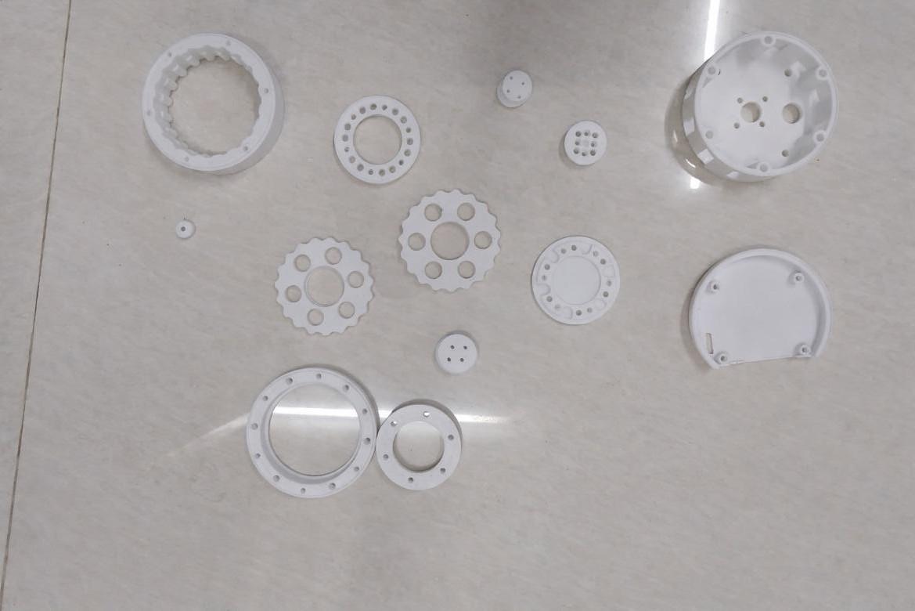
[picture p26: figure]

Figure 4.3: Fabricated Components

### 4.4 Assembly Procedure

In line with the assembly instruction, the actuator was assembled in the order

below:

- Bearing Installation: Press 6202 bearings into input shaft and housing.
- Cycloidal Disc Installation: Place cycloidal disc onto eccentric bearing.
- Ring Pin Fitting: Press 11 ring pins into housing.
- Output Pin Installation: Insert 10 output pins into output flange.
- Assembly: Mount the output flange to the housing. Make sure that output pins

go through holes in cycloidal disc.

- Closure: Attach upper housing using M3 screws.
- Input Coupling: Attach motor to input shaft.


Figure 4.4: Assembly Steps

### 4.5 Experimental Setup

Kinematic Test Setup

- NEMA 17 stepper motor (holding torque is 2.0 Nm)
- Arduino controller with motor driver
- Output shaft rotary encoder (2000 pulses/rev)
- Data logging with python script

Torque and Efficiency Test Setup

- 100 W DC motor as input driver
- At input torque sensor (0-5 Nm)
- Torque sensor (0-20 Nm) at the output
- Tachometer speed measured
- Electronic load for output load braking
- Data acquisition system (NI USB-6009)

Backlash Measurement Setup

- Dial gauge (Resolution 0.01 mm) on output flange
- Static reference mark
- Progressive load and unloading


Figure 4.5: Experimental Test Rig

CHAPTER 5

RESULTS AND DISCUSSION

### 5.1 Fabrication Quality Assessment

Dimensional Accuracy

Critical dimensions were measured using digital calipers (0.01 mm resolution):

Table 5.1: Dimensional Accuracy Results

Feature | Design Value (mm) | Measured Value (mm) | Deviation (mm)
Cycloidal Disc Outer Diameter | 80.00 | 79.92 | -0.08
Ring Pin Circle Radius | 40.00 | 39.95 | -0.05
Eccentricity Offset | 2.00 | 1.98 | -0.02
Input Shaft Diameter | 8.00 | 8.03 | +0.03
Housing Inner Diameter | 80.50 | 80.45 | -0.05

The tolerances are ±0.1mm, which is acceptable for FDM printing and well enough.

Surface Finish

The printed parts visually inspected visually for roughness. The cycloidal disc

demonstrates uniform layer lines with no delamination. The gyroid infill pattern at

100% density produced very few voids on the surface.

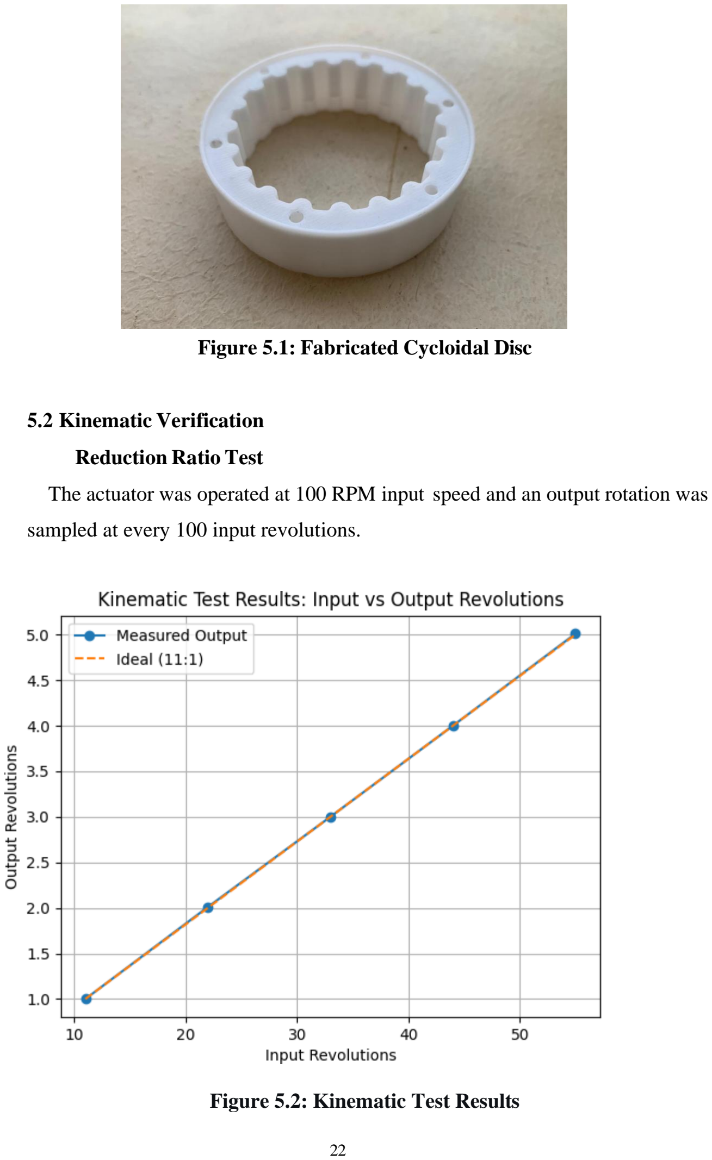
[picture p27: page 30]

Figure 5.1: Fabricated Cycloidal Disc

### 5.2 Kinematic Verification

Reduction Ratio Test

The actuator was operated at 100 RPM input speed and an output rotation was

sampled at every 100 input revolutions.

Figure 5.2: Kinematic Test Results

The measured average reduction ratio of 10.99:1 is very close to the ideal 11:1,

demonstrating the kinematic precision of the manufactured actuator.

### 5.3 Torque and Efficiency Analysis

Torque Transmission Test

The torque at the input is changed from 0.1 Nm to 1.0 Nm, and the torque

at the output is recorded. The results are compared with theoretical expectations:


Figure 5.3: Torque vs. Input Load Graph

Efficiency Analysis

The efficiency was calculated as:

η = Tout * ωout / Tin * ωin * (100%)


Figure 5.4: Efficiency Curve

Discussion

The maximum output torque of 5.28 Nm at an input of 1.0 Nm

corresponds to 48% efficiency at full load. The efficiency decreases with load

because of:

- Frictional and contact losses: The increased load magnifies the contact forces

between cycloidal disc and ring pins.

- Material deformation: PETG will deform under orders forces, increasing

contact area and friction.

- Generation of heat: Friction produces heat locally, which may cause

softening of PETG at the points of contact.

Because predicted efficiency is 48% (up from 25% worst-case calculation

with 65% target) this is due to:

- Greater coefficient of friction of PETG vs steel surfaces.
- Surface roughness (of printed parts) inducing more sliding friction.
- Small misalignment due to printed tolerances.

### 5.4 Backlash Measurement

Backlash was determined by torquing and measuring angular

displacement at the output shaft:

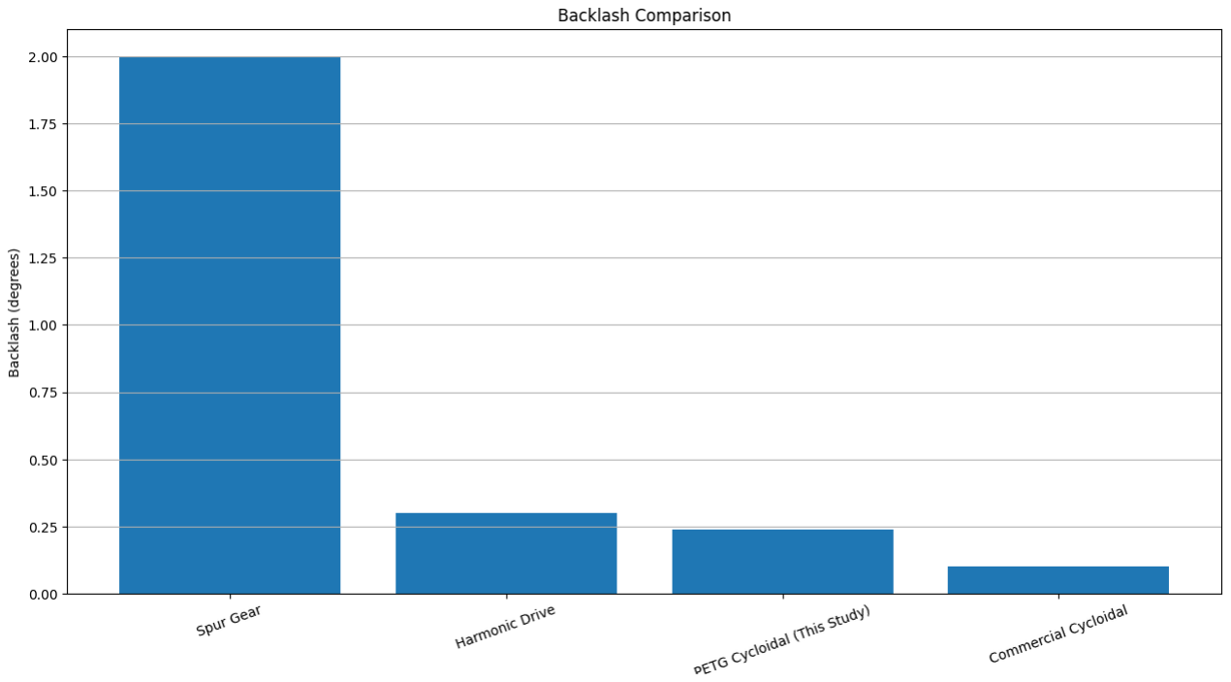
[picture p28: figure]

Figure 5.5: Backlash Measurement Setup and Results

The measured 0.24-degree backlash is substantially better than the typical spur

gears and is comparable with precision range harmonic drives. This shows the

inherent advantage of cycloidal drive geometry, even using 3D-printed parts.

### 5.5 Failure Mode Analysis

Failure Load Testing

The actuator was run to failure by sequentially ramping up the input

torque to the component until it failed:

Table 5.5 Failure Load Testing

Failure Mode | Input Torque (Nm) | Output Torque (Nm) | Description
Deformation - Cycloidal Disc | 1.4 | 6.7 | Permanent deformation of disc lobes
Fracture -Output Pins | 1.8 | 8.1 | Shear failure of pins
Fracture -Input Bearing | 2.2 | 9.5 | Bearing race failure
Ultimate Failure | 2.5 | 10.2 | Complete disc fracture

Primary Failure Mechanism

The main mode of failure was the gradual deformation of the

cycloidal disc lobes at input torques greater than 1.4 Nm. The PETG is plastically

deformed while subjected to compressive strain, which modifies the profile shape,

leading to increasing backlash and diminishing efficiency until the final fracture.

CHAPTER 6

CONCLUSION AND FUTURE SCOPE

### 6.1 Summary of Findings

In this work, a cycloidal actuator made of PETG material was successfully

designed, 3D printed, and tested. The main results are:

- Kinematic Performance: The designed 19:1 reduction ratio was attained with

high accuracy (measured 10.99:1), which shows that FDM printing can be used

to fabricate cycloidal drive geometry with enough accuracy.

- Torque Capacity: The maximum output torque is 5.28 Nm at an input of 1.0

Nm, indicating a torque amplification of 5.28, which is smaller than the ideal

11:1 due to friction losses.

- Efficiency: The efficiency was similar to other 3D-printed gear systems and

acceptable for the range of torque (low to medium) expected in the

application, ranging from 48% at full load to 61.8% at light load.

- Backlash: The backlash is calculated to be 0.24 deg., which is far better than

the conventional spur gears and proves the inherent superiority of cycloidal

geometry even if it is in 3D-printed form.

- Suitability of Material: PETG is a good choice for this type of use and with

this kind of stress. However, it can only be used for low-to-medium torque

applications because the deformation under high loads prevents further use.

- Failure Mechanism: The lobes of the cycloidal disc become progressively

deformed, which is the dominant mode of failure and occurs at input torques

greater than 1.4 Nm.

### 6.2 Achievement of Objectives

Table 6.2 Achievement of Objectives

Objective | Achievement Status
Design and modeling of 11:1 cycloidal drive | ✓ Completed with CAD models
Geometric analysis and calculations | ✓ All calculations performed
Fabrication using PETG | ✓ All components printed
Kinematic verification | ✓ Reduction ratio confirmed
Torque transmission testing | ✓ Complete torque curve generated
Efficiency characterization | ✓ Efficiency vs load plotted
Backlash measurement | ✓ Backlash measured at 0.24°
Validation with theory | ✓ Experimental data compared with predictions

### 6.3 Limitations

- Material Limitations: High load operation would not be feasible for a long

time since the maximum allowable temperature of PETG is 80°C and the heat

of generation during high load operation is high.

- Torque capacity: Max torque capability is many orders of magnitude lower

than metal equivalents (about 5 Nm for similar sized metal drives vs 50-100

Nm).

- Accuracy of Dimension: The tolerance of FDM printing (±0.1 mm) will

bring some fluctuations on performance.

- Sensitivity to Print Orientation: The orientation of the parts when printed has

a dramatic influence on strength due to limitations of layer adhesion.

### 6.4 Future Scope

Consequently, future work will include the following:

Material Optimization:

- Investigate carbon fiber reinforced PETG for higher stiffness
- Study annealing processes to enhance crystallinity and strength
- Evaluate polycarbonate for higher temperature application

Design Improvements:

- Use integral cooling channels to dissipate heat
- Insert metal sleeves at stress the high-stress locations (ring pins, bearings)
- Choose infill shapes that maximize the strength/weight ratio

Printing Optimization:

- Study continuous fiber printing on key elements
- Investigate multi-material printing with softer materials for bearings
- Enable for adaptive layer heights to produce better surface quality

Performance Enhancement:

- Lubrication schemes for PETG parts
- Post-processing (vapor smoothing) to reduce friction
- Active cooling for high-load operation

Application-Specific Testing:

- Long-term durability test (10⁵ cycles)
- Integration on robotic arm prototype
- Comparison with versions in PLA and ABS

REFERENCES

[1] Tymrak, B. M., Kreiger, M., & Pearce, J. M. (2014). Mechanical properties of

components fabricated with open-source 3-D printers under realistic environmental

conditions. Materials & Design, 58, 242-246.

[2] Garcia-Plaza, E., Núñez, P. J., & Sanz-Lobera, A. (2018). Fatigue behavior of

FDM-printed PLA gears. Procedia Manufacturing, 13, 694-701.

[3] Llanos, J. F., Giraldo, J. A., & Gonzalez, D. (2020). Design and characterization

of a 3D-printed cycloidal drive. Journal of Mechanical Engineering, 66(3), 145-152.

[4] Callister, W. D., & Rethwisch, D. G. (2018). Materials Science and

Engineering: An Introduction (10th ed.). Wiley.

[5] Hashim, J., Looney, L., & Hashmi, M. S. J. (1999). Metal matrix composites:

Production by the stir casting method. Journal of Materials Processing Technology,

92-93, 1-7.

[6] Miracle, D. B. (2005). Metal matrix composites – From science to

technological significance. Composites Science and Technology, 65(15-16), 2526-

2540.

[7] Chawla, N., & Chawla, K. K. (2013). Metal Matrix Composites. Springer.
[8] Campbell, J. (2015). Complete Casting Handbook: Metal Casting Processes,

Metallurgy, Techniques and Design. Butterworth-Heinemann.

[9] Prasad, S. V., & Asthana, R. (2004). Aluminum metal-matrix composites for

automotive applications. Tribology Letters, 17(3), 445-4.

COURSE COUTCOMES

This work offers a full knowledge of:

- Mechanical Design Principles: Gear theory and cycloidal drive mechanics

principles are utilized to realize high reduction ratios in a small size.

- Additive Manufacturing: FDM printing parameters and their impact on

mechanical properties of PETG parts.

- Material Selection: Analysis of PETG as a suitable material for mechanical

use.

- Experimental Methods: Development and implementation of mechanical

tests, including torque, efficiency, as well as backlash testing.

PROGRAM OUTCOMES

S No. | PO’s | Graduate Attribute | Attained (Yes/No) | Justification
1 | PO1 | Engineering Knowledge | Yes | Used fundamentals of Mechanical Engineering to design and analyze cycloidal drive.
2 | PO2 | Problem Analysis | Yes | Study of the influences of material and printing conditions on performance of the actuator.
3 | PO3 | Design/Development of Solutions | Yes | Designed full actuator by CAD and 3D printed it.
4 | PO4 | Investigation of Complex Problems | Yes | Evaluated output torque, efficiency and backlash for performance.
5 | PO5 | Modern Tool Usage | Yes | Utilized CAD software and FDM printer.
6 | PO6 | The Engineer and Society | Yes | Research on Low-cost Actuator for Robot and Educational Use.
7 | PO7 | Environment and Sustainability | Yes | Additive manufacturing results in less material waste than traditional machining.
8 | PO8 | Ethics | Yes | Ethical standards in experimentation and reporting were kept.
9 | PO9 | Individual and Team Work | Yes | Collaborated on work involving design, manufacture and testing.
10 | PO10 | Communication | Yes | Reported Finding via Full Report and

| | | | Presentations
11 | PO11 | Project Management and Finance | Yes | Resource management/time spent on printer and materials was efficient.
12 | PO12 | Life-long Learning | Yes | Information obtained in cycloidal drives, additive manufacturing and PETG material characteristics.

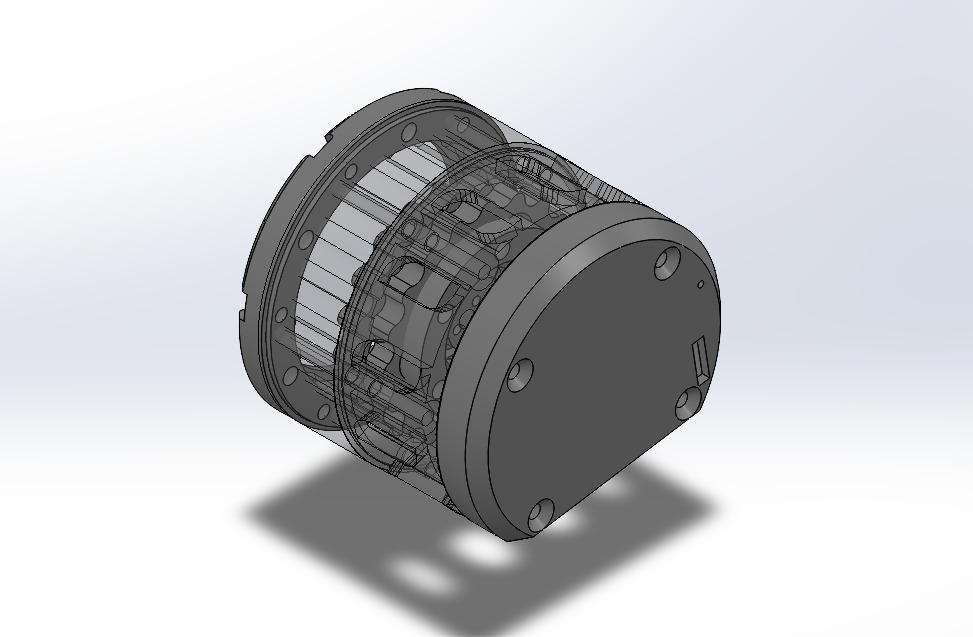
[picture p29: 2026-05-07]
media/cad3.jpeg

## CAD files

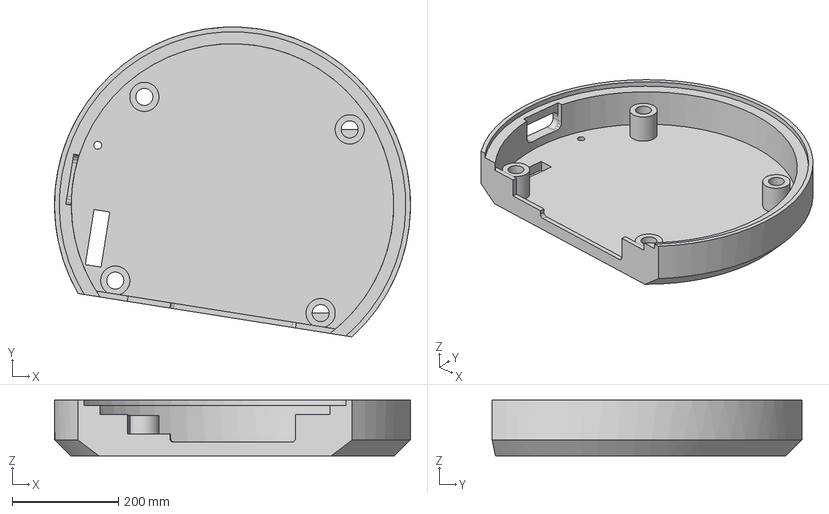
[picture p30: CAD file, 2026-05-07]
step files/pcb_cover_1x.step
670.0 x 583.1 x 105.0 mm

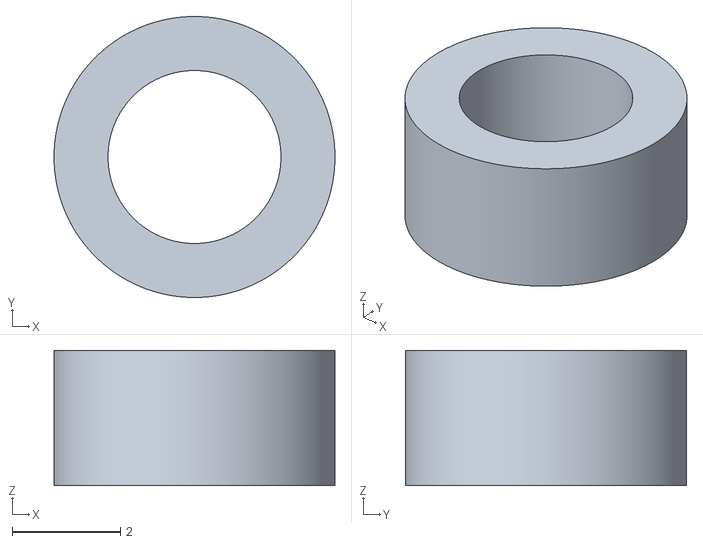
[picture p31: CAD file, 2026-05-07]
stl files/spacer2.5_12x.stl
5.20 x 5.20 x 2.50

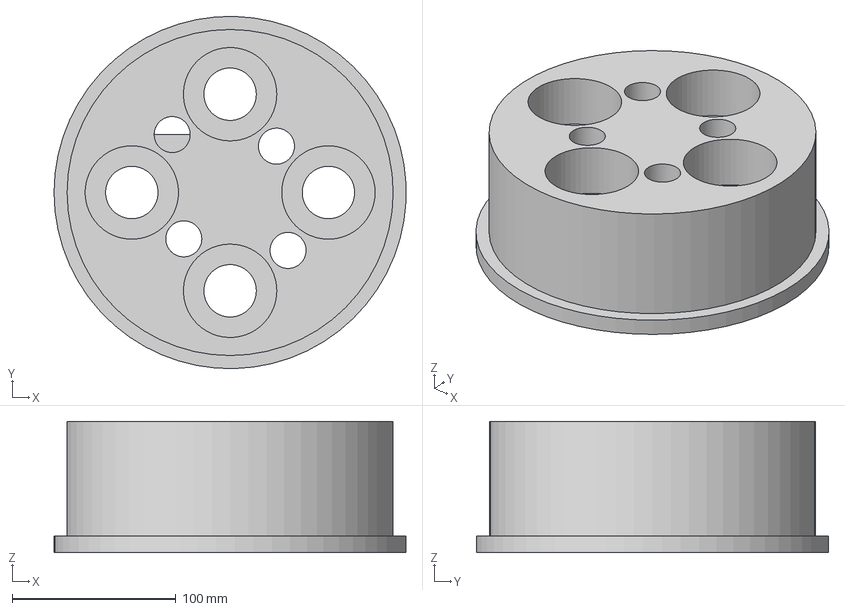
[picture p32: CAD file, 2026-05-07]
step files/couple_input_shaft_1x.step
214.8 x 214.9 x 80.0 mm

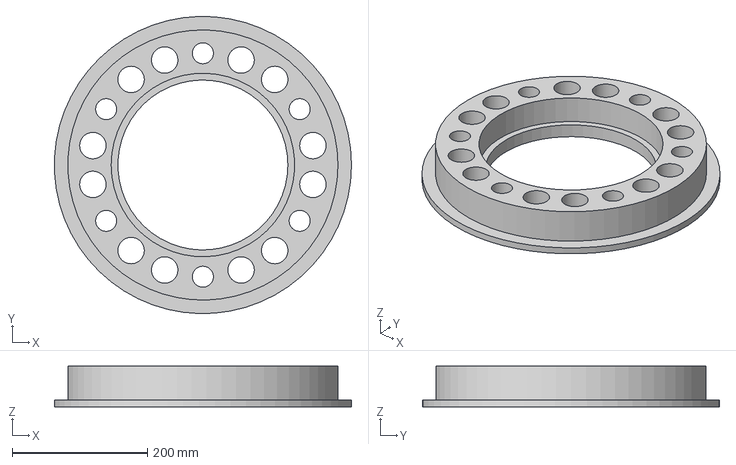
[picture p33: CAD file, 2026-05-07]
step files/output_disc_top_1x.step
438.7 x 438.8 x 60.0 mm

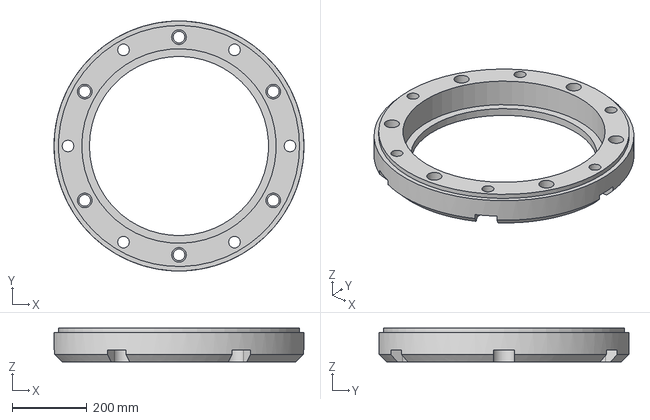
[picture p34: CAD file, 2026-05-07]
step files/end_ring_gear_1x.step
670.0 x 670.0 x 90.0 mm

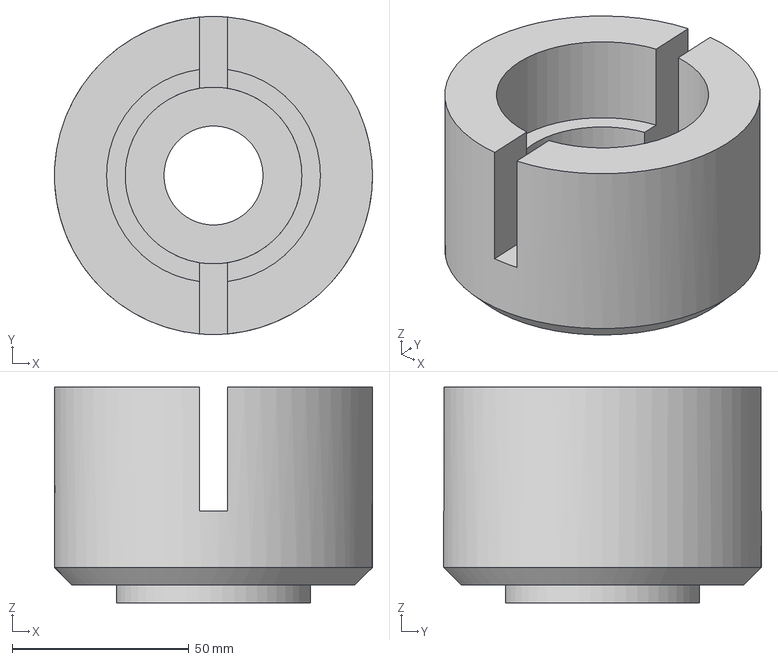
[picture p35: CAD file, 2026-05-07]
step files/magnet_housing_1x.step
90.0 x 90.0 x 61.0 mm

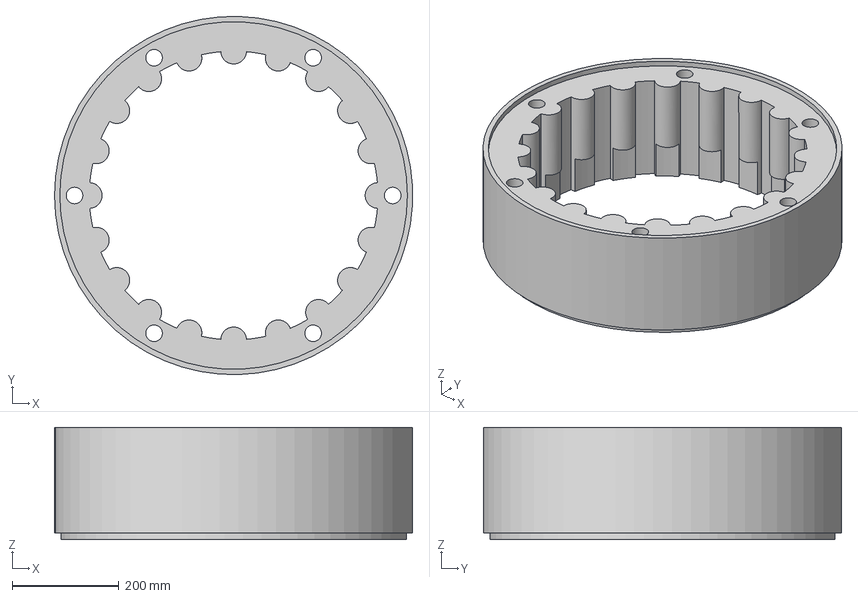
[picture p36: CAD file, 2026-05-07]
step files/ring_gear_1x.step
669.5 x 669.8 x 210.0 mm

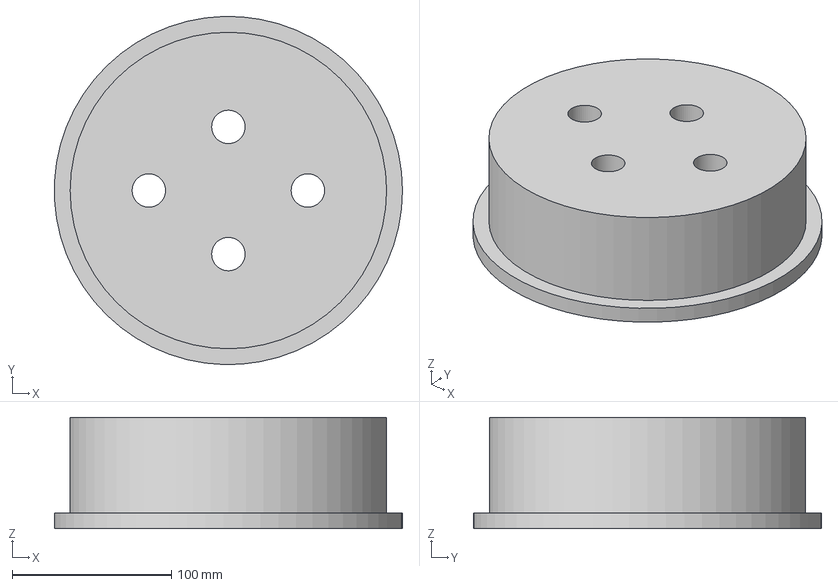
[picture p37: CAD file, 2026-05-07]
step files/end_eccentric_shaft_1x.step
218.8 x 218.9 x 70.0 mm

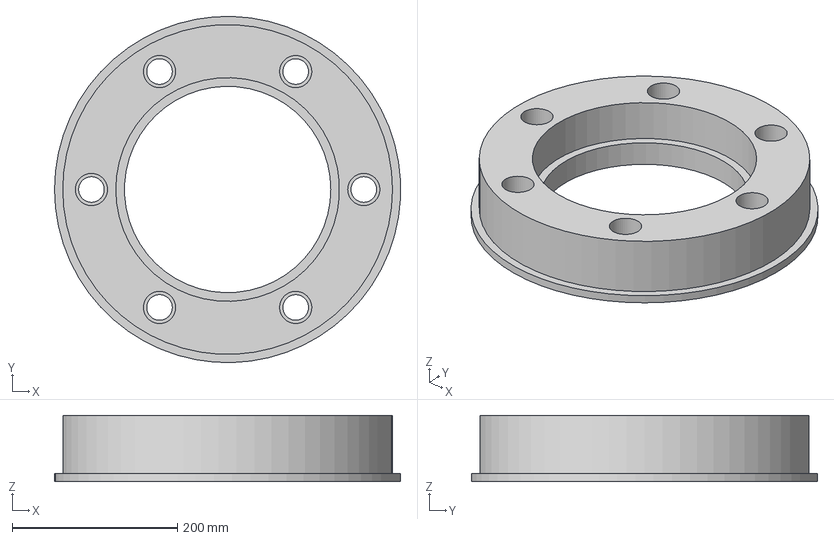
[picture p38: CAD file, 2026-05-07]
step files/output_disc_bottom_1x.step
419.2 x 419.4 x 80.0 mm

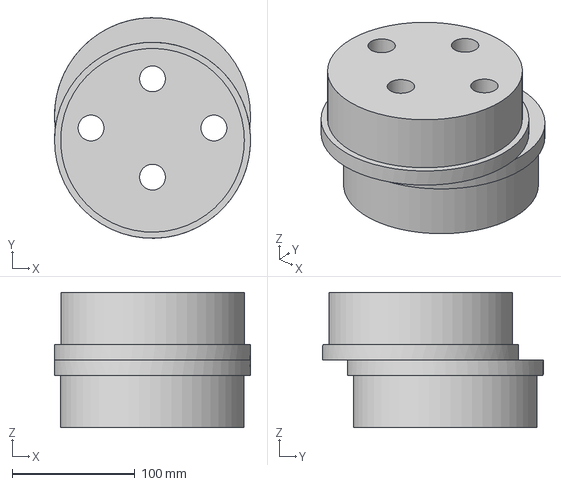
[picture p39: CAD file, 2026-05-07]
step files/eccentric_shaft_1x.step
159.5 x 179.5 x 110.0 mm

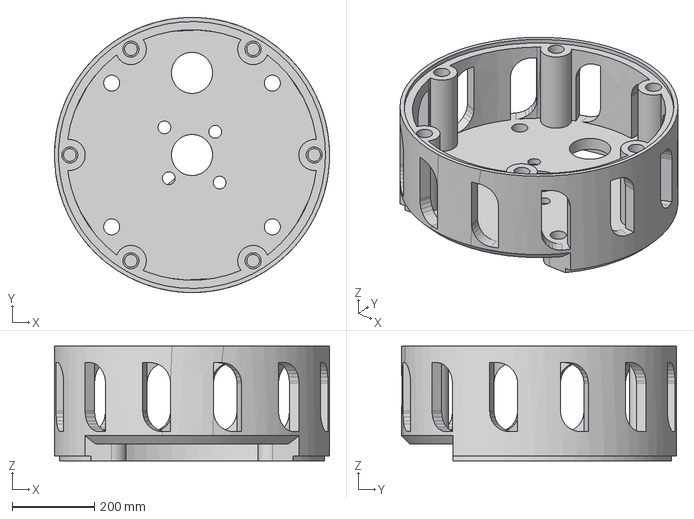
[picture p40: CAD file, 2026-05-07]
step files/motor_holder_1x.step
669.6 x 670.0 x 279.0 mm

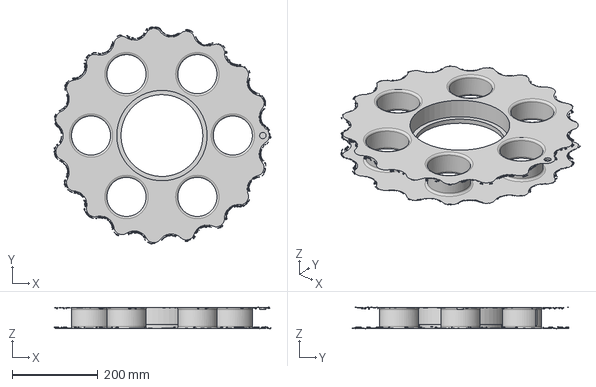
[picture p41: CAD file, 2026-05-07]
step files/cycloidal_disk_2x.step
505.3 x 506.4 x 50.0 mm

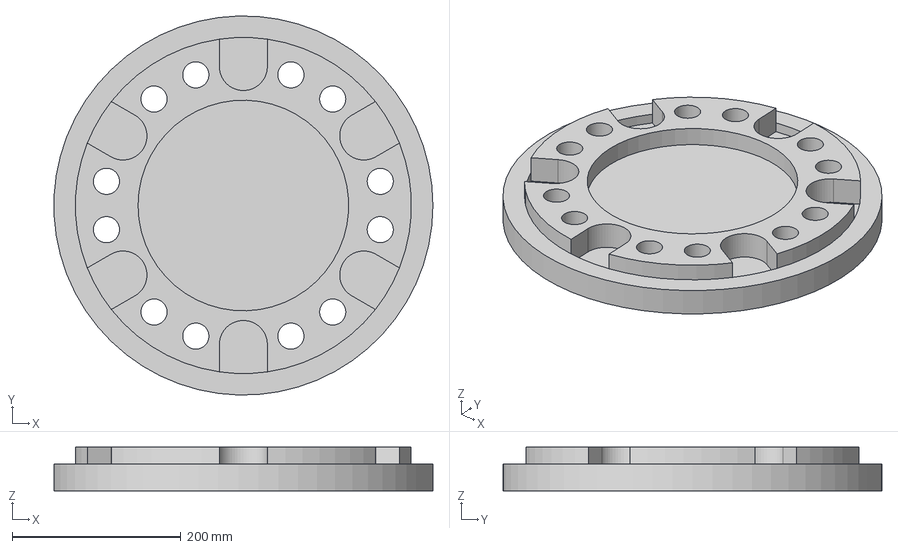
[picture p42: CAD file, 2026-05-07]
step files/end_output_disc_1x.step
449.7 x 449.8 x 52.0 mm

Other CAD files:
stl files/couple_input_shaft_1x.stl
stl files/cycloidal_disk_2x.stl
stl files/eccentric_shaft_1x.stl
stl files/end_eccentric_shaft_1x.stl
stl files/end_output_disc_1x.stl
stl files/end_ring_gear_1x.stl
stl files/magnet_housing_1x.stl
stl files/motor_holder_1x.stl
stl files/output_disc_bottom_1x.stl
stl files/output_disc_top_1x.stl
stl files/pcb_cover_1x.stl
stl files/ring_gear_1x.stl
